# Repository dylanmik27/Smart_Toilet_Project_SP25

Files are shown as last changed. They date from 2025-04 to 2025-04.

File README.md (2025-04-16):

# Smart_Toilet_Project_SP25
Automated Toilet Seat Controller
An automated toilet seat system designed to enhance hygiene and convenience in bathrooms. This project integrates sensor inputs and actuator control using a microcontroller running MicroPython. The system uses a PIR motion sensor to detect proximity, a pressure switch to sense occupancy, a servo for seat actuation, and a speaker for audio feedback.

# Table of Contents
- [Overview](#overview)
- [The Circuit](#the-circuit)
- [Parts List](#parts-list)
- [Features](#features)
- [Hardware Requirements](#hardware-requirements)
- [Software Structure](#software-structure)
- [Setup & Installation](#setup--installation)
- [Usage](#usage)
- [Versions](#external-specifications-on-software-and-firmware-versions)

# Overview
The Automated Toilet Seat Controller automates the operation of a toilet seat based on user presence and interactions. When the PIR sensor detects motion near the toilet, the system opens the seat by actuating a servo. It then waits for the user to sit down (detected via a pressure switch connected between ground and gp15) and later to stand up. Once the user leaves, the system delays for a predetermined period before closing the seat. Audio tones are played during both the opening and closing operations to provide audible feedback.

# The Circuit
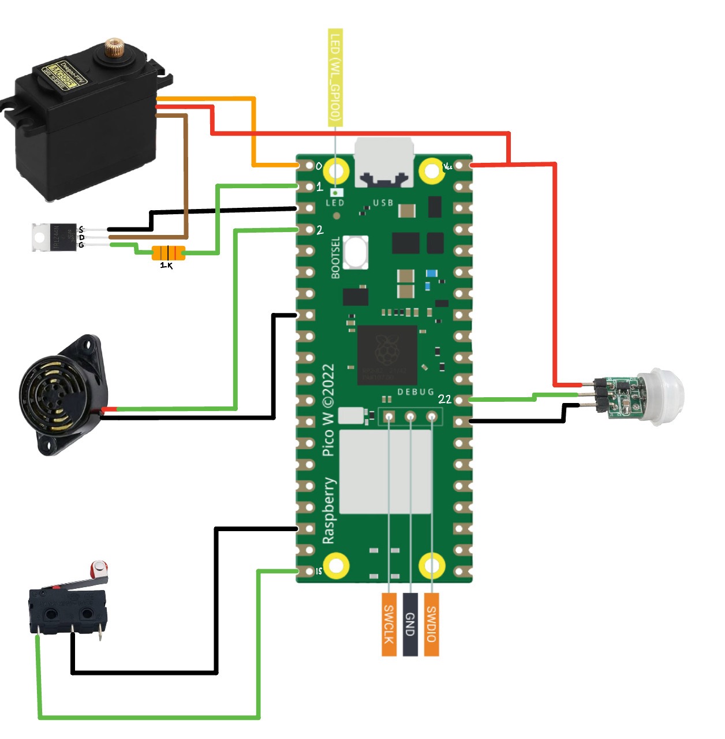
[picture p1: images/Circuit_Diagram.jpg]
Circuit Diagram


# Parts List
| Component | Part Name/Number | Quantity Needed | Amazon Link |
|---|---|---|---|
| Servo Motor | MG995 servo motor | 1 | [link](https://www.amazon.com/Control-Angle180-Digital-Torque-Helicopter/dp/B0D7M4LHBP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) |
| Motion Sensor | Mini Pyroelectric PIR Motion Sensor Module | 1 | [link](https://www.amazon.com/DIYables-Pyroelectric-Infrared-Detector-Raspberry/dp/B0CSD2K25B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) |
| Limit Switch | HiLetgo 10pcs Micro Limit Switch KW12-3 | 1 | [link](https://www.amazon.com/HiLetgo-KW12-3-Roller-Switch-Normally/dp/B07X142VGC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) |
| Speaker | SFM-27 DC 3-24V Electronic Piezo Buzzer | 1 | [link](https://www.amazon.com/Stemedu-Decibel-Sounder-Electronic-Continuous/dp/B096P5K9W1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) |
| MOSFET | IRLZ44N IRLZ44 MOSFET Transistor | 1 | [link](https://www.amazon.com/ALLECIN-IRLZ44N-Transistors-IRLZ44NPBF-Mosfets/dp/B0CBKH4XGL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) |
| Micro-Controller  | Raspberry Pi Pico W | 1 | [link](https://www.amazon.com/Raspberry-Pi-Pico-Development-Integrated/dp/B0BDLHMQ9C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) |

# Features
Motion Detection: Uses a PIR sensor connected to a designated GPIO pin to monitor activity.

Occupancy Sensing: Incorporates a pressure switch to determine if someone is sitting on the toilet seat.

Servo Actuation: Controls the movement of the toilet seat with precise servo motor actions.

Audio Feedback: Utilizes a speaker to play tones or a jingle during key operations (opening/closing the seat).

Modular Design: Code is organized into separate modules for motion detection, servo control, and sound generation, simplifying development, maintenance, and testing.
> Also mechanically modular, with multiple part being able to be designed for different toilet seats, and applications(trashcan)

# Hardware Requirements
Microcontroller: Raspberry Pi Pico running MicroPython.

PIR Motion Sensor (DIYables mini pyroelectric PIR): Connected to GPIO Pin 22 for motion detection.

Pressure Switch (HiLetgo limit switch): Connected to GPIO Pin 15 (with an internal pull-up resistor) to sense seat occupancy.

Servo Motor (MG995): Controlled via PWM (using GPIO Pin 0) with an additional control switch (GPIO Pin 1) as required by the servo circuit.
> IRLZ44N Transistor to switch power to the Servo.

Speaker (Stemedu Piezo Active Buzzer): Driven by PWM on GPIO Pin 2 for audio output.

3D Pritned Components: to deal with actuation.

# Software Structure
> The project is organized into multiple files, each encapsulating a specific aspect of the system:

main.py:
>Acts as the central controller. It initializes all modules, plays startup tones, performs an initial servo test, and enters the main loop where it monitors the PIR sensor. Upon detecting motion, it triggers the servo to open the seat, waits for the pressure switch to >sense occupancy changes, and finally commands the servo to close the seat after specified delays while providing audio feedback.

Motion.py:
>Contains the logic for initializing the PIR sensor and updating a flag based on motion detection. It provides a simple function to check the sensor state.

Servo_Control.py:
>Manages servo motor actuation using PWM. It calculates duty cycle values for the desired open and closed angles, provides functions to open and close the seat, and includes a test function for simulating movement. Audio feedback is integrated into these functions.

Speaker.py:
>Controls the speaker output by defining a melody and providing functions to play individual tones or sequences (jingles). It is used by the servo module to provide confirmation sounds during seat movement.

Main_control.py:
>Contains legacy code that was used during servo development and is kept for reference and documentation purposes. It is not actively executed when the device is in operation.

# Setup & Installation
# Hardware Setup:

Connect the PIR sensor to GPIO Pin 22.

Wire the pressure switch between ground and GPIO Pin 15.

Connect the servo motor to the designated PWM output (GPIO Pin 0) and link the control switch (IRLZ44N transistor) to GPIO Pin 1.

Attach the speaker to GPIO Pin 2.

Ensure all power and ground connections are secure.

# Mechanical Setup

3d print all provided STLs as they are all necessary for full assembly.
>print in a durable material (petg was used in this case) Glass or Carbon filled filaments may work well for its durability

Attach servo to bracket using 10-24 x 1/2 screws

Utilize cable shielding out of the Brain Case to ensure water resistance.

Mount piezo speaker inside Brain Case using 8-32 x 1/2 screws.

Remove toilet bolt on the right hand side and insert and retighten through servo bracket.

Attach switch to side of toilet with VHB tape.

Attach flat board and Magic eraser to under side of seat using VHB tape.

Perform Software Installation.

Initialize entire project and unplug device when servo moves once.

Attach servo arm using provided screw.

Attach a command hook near bottom of toilet.

Attach 2 rubber bands between the command hook and servo arm.
>Can be adjust depending on weight of seat

# Software Installation:

Install MicroPython on your microcontroller if not already done.

Clone or download this repository to your development environment.

Upload the files (main.py, Motion.py, Servo_Control.py, Speaker.py) to the microcontroller.

# Usage
After completing the setup:

Power up the microcontroller.

The main.py script will run automatically, initializing the system by playing a series of tones.

The servo will perform an initial test of opening and closing the seat.

The system continuously monitors the PIR sensor. When motion is detected, the seat opens.

The system then waits for a user to sit on the seat (pressure switch activated) and to stand up, after which the seat will close after a short delay.

Audio feedback is provided during both the opening and closing operations.

# External specifications on software and firmware versions
* MicroPython v1.24.1 
* Raspberry Pi Pico W with RP2040
* Python version - 3.13.1

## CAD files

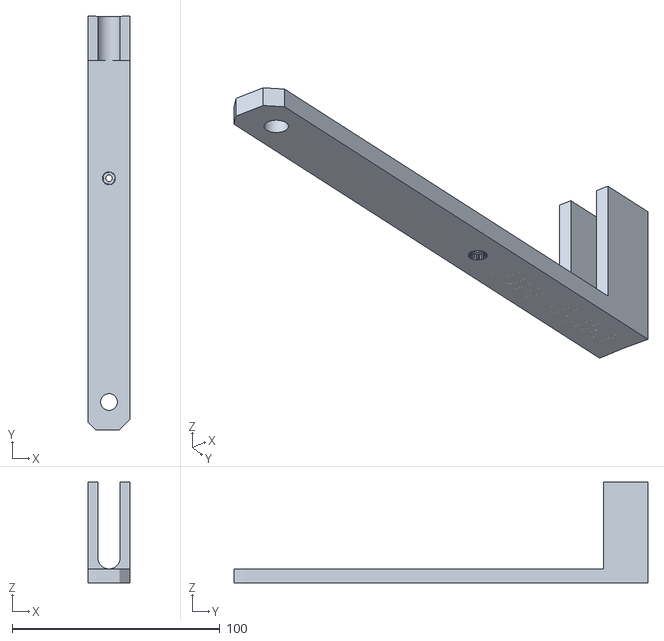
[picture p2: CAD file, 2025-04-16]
3D_Models/TOILET_SERVO_ARM.stl
20.2 x 199.2 x 48.5

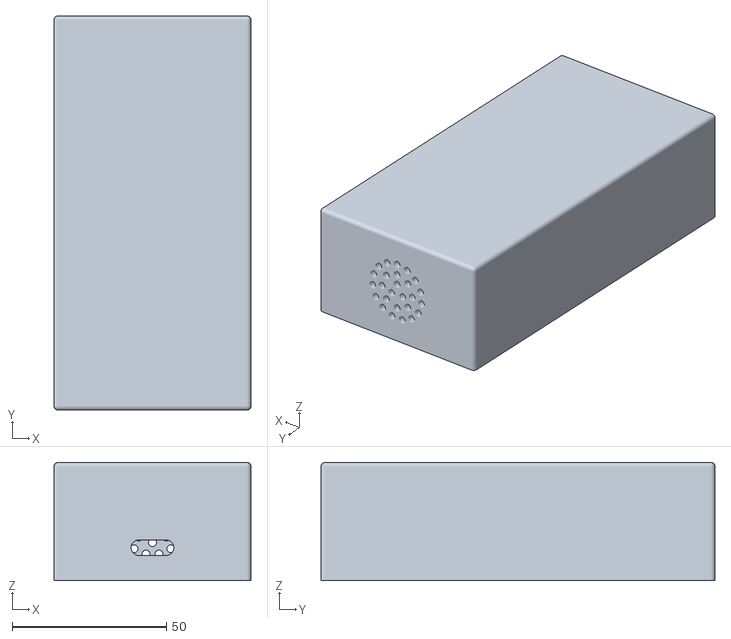
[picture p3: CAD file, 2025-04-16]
3D_Models/TOILET_LID.stl
63.8 x 127.6 x 38.3

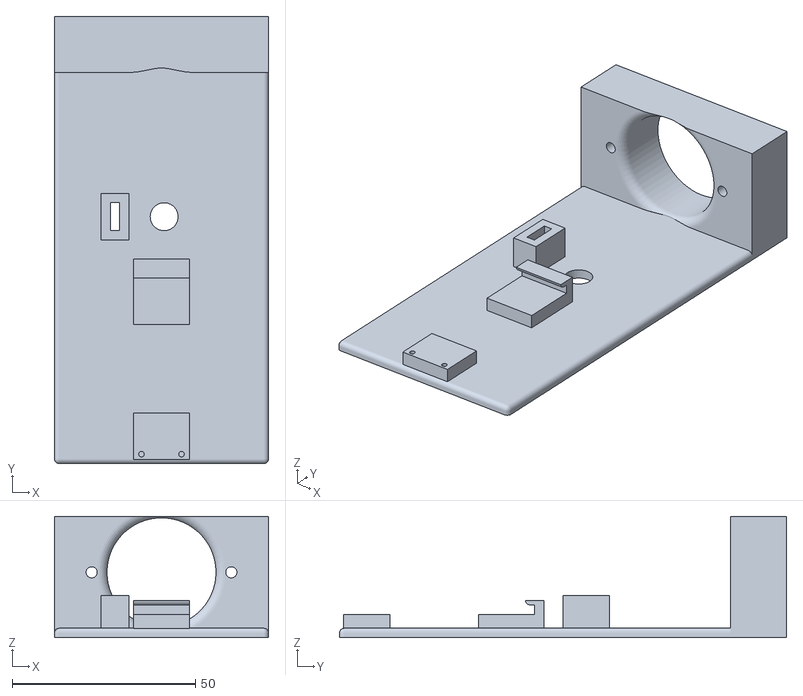
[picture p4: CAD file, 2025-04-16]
3D_Models/TOILET_BRAINBOX_BASE.stl
58.4 x 121.9 x 33.0

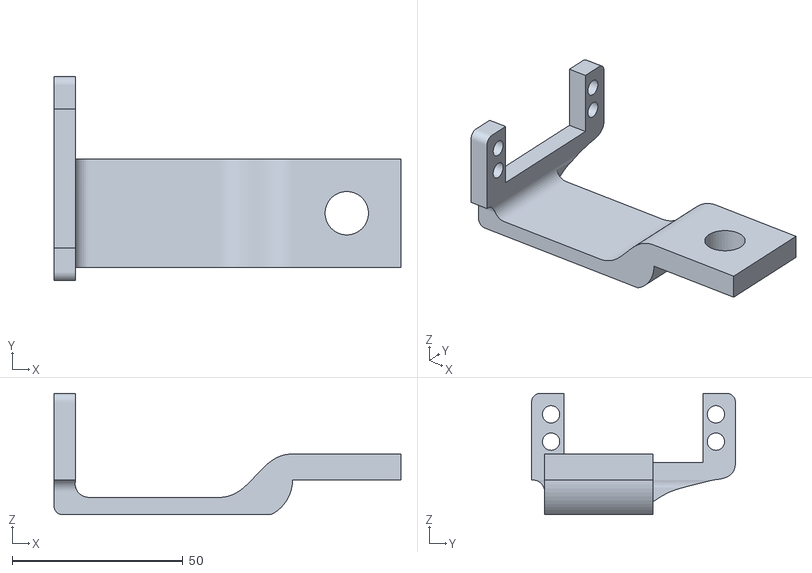
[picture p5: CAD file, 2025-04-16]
3D_Models/TOILET_SERVO_BRACKET.stl
101.6 x 59.7 x 35.6

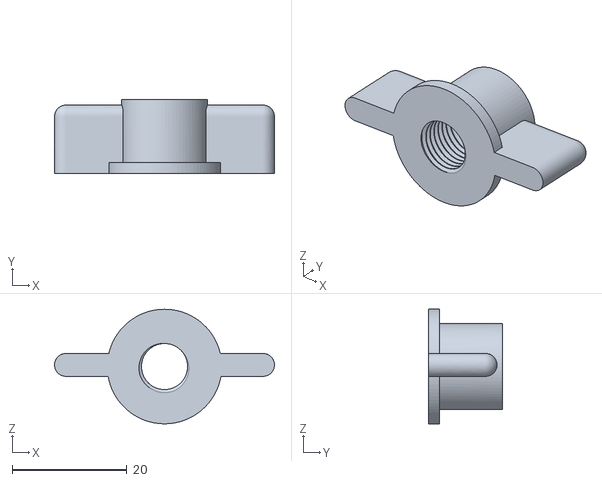
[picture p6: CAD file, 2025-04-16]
3D_Models/TOILET_NUT.stl
38.4 x 13.0 x 20.0

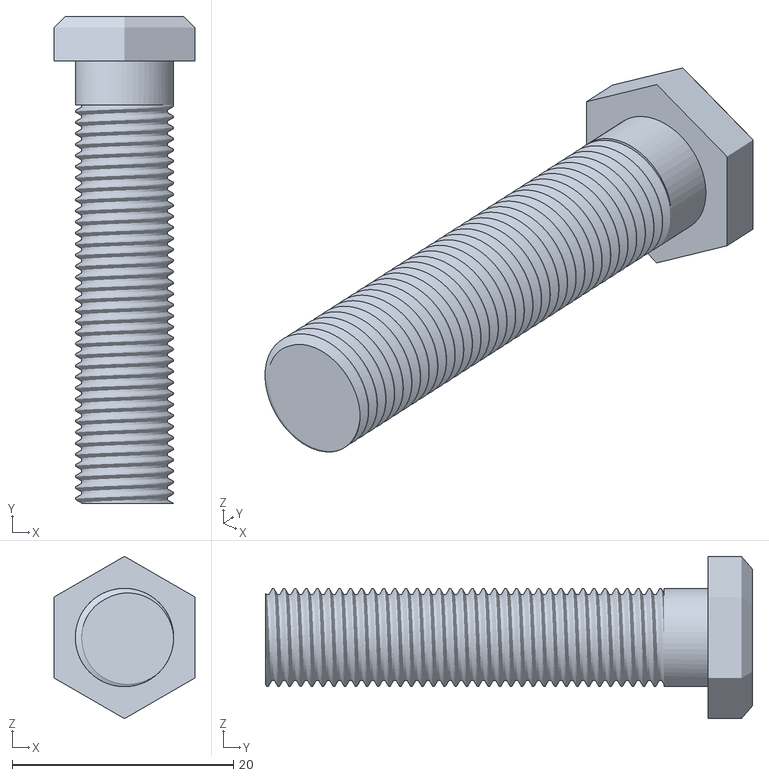
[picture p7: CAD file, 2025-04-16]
3D_Models/TOILET_BOLT.stl
12.7 x 44.0 x 14.7

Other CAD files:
3D_Models/TOILET_PARTS.f3d

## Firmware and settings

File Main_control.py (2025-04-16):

#Legacy code that remnains from the servo development, utilized to implement main.py
#Code is not ran when device is operated, and only remains for documentation

from machine import Pin
from utime import sleep
import Servo_Control
#print("starting code")
#momentary switch connected between pin 15 and ground
#Servo_Control.test_move()
#print("test completed")
# initialize pin 20 as input w/ pull up resistor
button = Pin(15, Pin.IN, Pin.PULL_UP)

#initialize initial condition for assembly
Servo_Control.close_servo()
while button.value() != 0:
    continue
#print("button")
#loop for test
#Servo_Control.open_servo()
#Servo_Control.close_servo()

while True:
    if button.value() == 0:  # pressed
        #print("button")
        #print(Servo_Control.is_open)
        if Servo_Control.get_open() == True: 
            Servo_Control.close_servo()
        else:
            Servo_Control.open_servo()
        sleep(0.1)  # debounce

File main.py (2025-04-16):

#This main.py script serves as the central controller for the automated toilet seat project. 
# It integrates inputs from both a PIR sensor and a seat pressure switch with actuator control through a servo and provides audio feedback via a speaker. 
# Upon startup, the script plays a series of tones and performs an initial test by opening and closing the seat. 
# During operation, it continuously polls the PIR sensor, and once motion is detected, 
# it triggers the servo to open the seat and then waits for user interaction via the seat switch—first detecting when someone sits down and then when they stand up. 
# After these inputs, it plays another tone and incorporates delays before closing the seat. 
# In summary, this code orchestrates sensor readings, mechanical seat movements, and sound signals to provide a seamless, automated toilet seat experience.

#print message via UART to confirm proper connection
print("import")

#import necessary dependencies, and other modules designed to be implemented in this script
    #native machine dependencies
from machine import Pin
import time
    #developed modules
import Servo_Control
import Motion
import Speaker

#create a input pin for the switch actuated by seat pressure
seat_switch = Pin(15, Pin.IN, Pin.PULL_UP)
#play initialize tones
Speaker.play_tone(660, 0.15)
Speaker.play_tone(880, 0.3)
#print message via UART to confirm proper series
print("loaded")
#test move
Servo_Control.open_servo()
Servo_Control.close_servo()

#Main Loop
while True:
    #wait between detection
    time.sleep(1)
    Motion.detect_motion()
    if Motion.motion_detected:
        Servo_Control.open_servo()
        #while seat has not been sat on loop with time delay
        while seat_switch.value() != 0:
            time.sleep(0.1)
        #while seat is still sat on loop with time delay
        while seat_switch.value() == 0:
            time.sleep(0.1)
        #play tone to verify closing timer started
        Speaker.play_tone(440,.15)
        time.sleep(30)
        Servo_Control.close_servo()
        #wait until user has left, so PIR no longer experiences input
        time.sleep(30)
    else:
        time.sleep(1)

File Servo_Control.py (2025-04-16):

#This module manages servo actuation using PWM on a microcontroller. 
# It initializes a servo output and a control switch, sets the PWM frequency to 50Hz (Per the MG995 datasheet), 
# and calculates duty cycle values for specified open and closed angles using a conversion function. 
# The module provides functions to open and close the servo—which also trigger a short jingle for audio feedback
# and maintains a state flag to track the servo position. Additionally, it offers a test function to simulate movement.

#import necessary dependencies, and other modules designed to be implemented in this script
    #native machine dependencies
from machine import Pin, PWM
from time import sleep
    #developed modules
import Speaker

#initialize the pins where the servo and transistor are connected
servo = PWM(Pin(0))     # the Pico PWM pin
servo_switch = Pin(1, Pin.OUT)
#set servo PWM frequency to 50Hz
servo.freq(50) #per the mg995 datasheet 50hz
#set two angles 90 degrees apart, these for chose for adjustability in each direction, and only are necessary when syncronizing the servo arm
s_closed_angle = 120
s_open_angle = 30
#create a global flag to determine state of servo.
is_open = False

#the duty cycle to open the servo given by formula: Duty = ((0.5 + (Angle / 90)) /20 )*100
def convert_angle(angle):
    percentage = ((0.5 + (angle / 90)) /20 )
    return int(percentage * (2**16 - 1))

#store and print duty cycle values
servo_closed_val = int(convert_angle(s_closed_angle))
servo_open_val = int(convert_angle(s_open_angle))
print(servo_closed_val)
print(servo_open_val)


#this function closes the servo
def close_servo():
    global is_open
    #allow current to flow through transistor
    servo_switch.value(1)
    #move servo to close
    servo.duty_u16(servo_closed_val)
    #play jingle
    Speaker.jingle()
    sleep(2) #wait for servo to move
    #set global variable to closed
    is_open = False
    #stop PWM and servo voltage
    servo.deinit
    servo_switch.value(0)
    return

def open_servo():
    global is_open
    #allow current to flow through transistor
    servo_switch.value(1)
    #move servo to open
    servo.duty_u16(servo_open_val)
    #play jingle
    Speaker.jingle()
    sleep(2) #wait for servo to move
     #set global variable to open
    is_open = True
        #stop PWM and servo voltage
    servo.deinit
    servo_switch.value(0)
    return

#return state of is_open
def get_open():
    return is_open

#legacy test code
#arbitrary test using defined values
def test_move():
    servo.duty_u16(6371)  
    sleep(2)                          
    servo.duty_u16(2730)  
    sleep(5)
    servo.deinit()           
    return

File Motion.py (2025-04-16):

#This module sets up a PIR sensor on a microcontroller by configuring a specific pin as input. 
# It maintains a Boolean flag to indicate whether motion is detected and defines a function to update this flag based on the sensor's digital state. 
# Commented-out test code demonstrates how the function could be used in a loop for continuous monitoring.

#import necessary dependencies
from machine import Pin
from time import sleep

# Define the PIR sensor input pin
motion = Pin(22, Pin.IN)

# Flags to indicate motion detection state
motion_detected = False

# Callback function to handle motion detection
def detect_motion():
    global motion_detected
    if motion.value() == 1:  # Rising edge (motion detected)
        motion_detected = True
    else:  # Falling edge (motion stopped)
        motion_detected = False


#Test code utilized in file to verify function of PIR sensor
    # while True:
    #     detect_motion()
    #     if motion_detected:
    #         print("Motion detected!")
    #     else: 
    #         print("oh no")
    #     sleep(1)  # Main loop delay

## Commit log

2025-03-03 Edited main, and Servo_Control for servo testing
2025-03-03 fixed error with typecasting
    [Main_control.py, Servo_Control.py]
2025-03-03 pin fix
2025-03-03 Complete servo test using button
2025-03-13 Change angle value, for elastic driven Servo
2025-03-13 Create noise on Piezo
    [Main_control.py, Speaker.py]
2025-04-06 added transistor on pin 1 to enable Servo
2025-04-06 Motion Sensor Stuff
2025-04-07 utilized Flynn's code to implement motion sensor
2025-04-12 ajust servo direction and main to have cues
2025-04-12 moving servo test code to main
2025-04-15 Added the utilized 3D models
    [TOILET_BOLT.stl, TOILET_BRAINBOX_BASE.stl, TOILET_LID.stl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]
2025-04-15 added circuit Circuit_Diagram
2025-04-15 Update README.md
    update readme to display circuit
